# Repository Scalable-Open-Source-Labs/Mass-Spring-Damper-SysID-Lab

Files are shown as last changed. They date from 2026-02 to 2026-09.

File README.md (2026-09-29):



# Mass Spring Damper SysID Lab

A low-cost dynamics lab that allows students to perform System Identification on a real Mass-Spring-Damper system.

This is the source repo where you can download files for manufacturing: hardware, firmware, and enclosure design files. If you're looking for usage instructions or lab notes, head to the [user guide](https://monasheng.gitbook.io/scalable-labs/mass-spring-damper-sysid).

*Designed by Michael Ruppe for Monash University in partnership with MathWorks®*

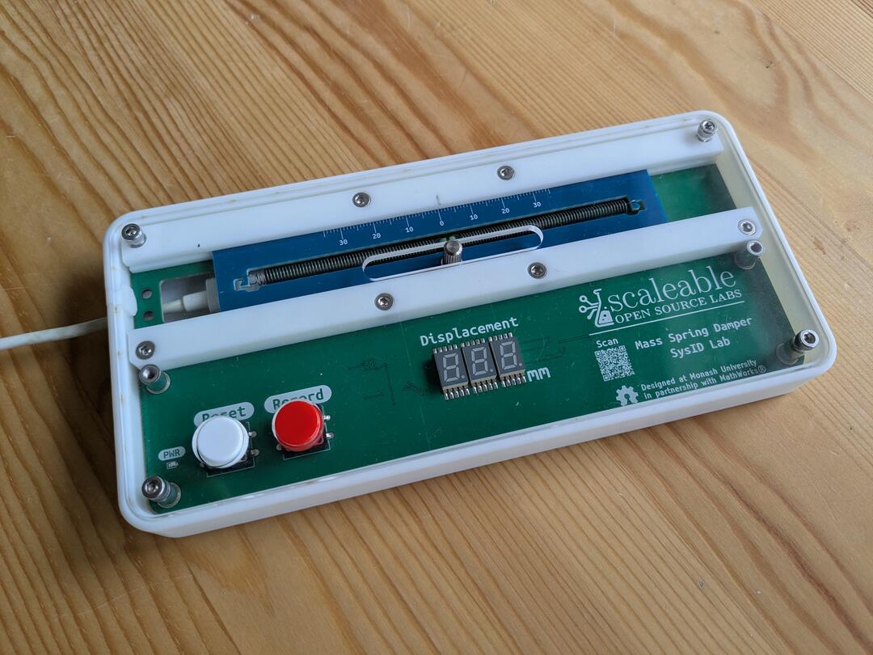
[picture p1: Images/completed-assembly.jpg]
Mass-spring-damper system diagram


## Repo map

| Path | What it is |
|---|---|
| [`PCB/`](PCB/README.md) | KiCad hardware source for the main board and carriage |
| [`Enclosure/`](Enclosure/README.md) | 3D-printable case, guide rail, and lasercut acrylic lid |
| [`firmware-mass-spring-damper-sys-id-lab/`](firmware-mass-spring-damper-sys-id-lab/README.md) | Arduino sketch for the RP2040 main board |
| [`Images/`](Images/) | Photos used in the assembly guide |
| [`Assembly-Instructions.md`](Assembly-Instructions.md) | Step-by-step mechanical build guide |
| [`Programming-Instructions.md`](Programming-Instructions.md) | Flashing and firmware dev setup |
| [`Ordering-Instructions.md`](Ordering-Instructions.md) | Bill of materials and where to order/fabricate each part |
| [`JLCPCB-Ordering-Instructions.md`](JLCPCB-Ordering-Instructions.md) | Step-by-step JLCPCB order for the fabricated and assembled boards |
| [`RELEASING.md`](RELEASING.md) | Maintainer checklist for cutting a tagged release |

## Getting started

- [Ordering Instructions](Ordering-Instructions.md)
  - [JLCPCB Ordering Instructions](JLCPCB-Ordering-Instructions.md)
- [Assembly Instructions](Assembly-Instructions.md)
- [Programming Instructions](Programming-Instructions.md)
- [Latest Project Release](https://github.com/Scaleable-Open-Source-Labs/Mass-Spring-Damper-SysID-Lab/releases/latest) - A downloadable bundle of all project files to complete this project: 3D Printing, PCBA, Lasercutting

## License

This project is licensed under the [MIT License](LICENSE).

Bundled third-party content — KiCad symbol/footprint libraries and vendor 3D step models under `PCB/main-board/packages3D/` and `PCB/carriage/CAD/`, and the patched `LedControl` fork used by the firmware (see [firmware README](firmware-mass-spring-damper-sys-id-lab/README.md)) — retains its original license terms.

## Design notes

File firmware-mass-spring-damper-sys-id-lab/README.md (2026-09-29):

# Firmware

Arduino sketch for the RP2040 main board. It reads the linear encoder as the carriage moves, drives the 7-segment display, and exposes the captured motion data as a CSV over USB. The board enumerates as a mass-storage drive, so data can be pulled off without any host-side software.

For build/flash setup (Arduino IDE, board settings, library versions) and calibrating a unit whose encoder misbehaves, see [Programming-Instructions.md](../Programming-Instructions.md).

The calibration maths and the encoder decoder have host tests that run on a PC. See [firmware-tests](../firmware-tests/README.md).

## Files

| File | Role |
|---|---|
| `firmware-mass-spring-damper-sys-id-lab.ino` | Main sketch: mode state machine, encoder capture, CSV data buffer, test mode |
| `gpio.cpp` / `gpio.h` | Pin definitions and GPIO init for the encoder, button, and display. Per-channel comparator thresholds (PWM through an RC filter) and sensor voltage readings (ADC) |
| `calibration.cpp` / `.h` | Per-unit threshold calibration, saved to emulated EEPROM |
| `sweep.cpp` / `.h` | Calibration-mode sweep recording and analysis: where each comparator actually switches, the width of each encoder state, and the thresholds that space the edges best |
| `LedControlPatched.cpp` / `.h` | Fork of the [LedControl](https://wayoda.github.io/LedControl/) library, with local modifications, used to drive the 7-segment display |
| `ramdisk.h` | USB Mass Storage (virtual FAT drive) implementation used to export captured data as a CSV file. The 32 KB image holds about 2,500 rows; `generateCSV()` stops at the last whole row that fits and reports it on serial |

## Encoder thresholds

Each optical channel's comparator switches at its own threshold, set by PWM through a 10k/1µF filter. An uncalibrated unit uses 780 mV on every channel (`VREF_DEFAULT_MV` in `gpio.h`).

The three channels form a 6-state Johnson code, and each state should span 1 mm of the 6 mm strip period. Robustness is the width of the narrowest state. When it reaches 0, two channels switch at the same place and a count can be lost.

A threshold moves its channel's two edges in opposite directions, so thresholds can only trade width between opposite states (100/011, 110/001, 111/000). The narrowest state is widest when every channel reads light for exactly half of each period (50% duty).

Calibration therefore sets each channel's threshold for 50% duty, measured from a sweep. This is not the midpoint of the channel's light and dark levels:
- The light level clips, because the phototransistor saturates near 220 mV. That lifts the midpoint, so a midpoint threshold makes every channel light for more than half the period.
- Calibration version 1 used the midpoint, and on a clipping sensor it pushed two channels' edges together. Units calibrated that way revert to the defaults (`CAL_VERSION` 2).

The rules:
- Each switching point stays at least 200 mV inside the sweep's light and dark levels (`MIN_MARGIN_MV` in `sweep.h`). If 50% duty lies outside that window, the threshold stops at the margin.
- When a margin stops a channel short of 50%, the others give way. Pushing them to 50% regardless would squeeze a state between them and the stuck channel.
  - Calibration starts from 50% duty, or from the thresholds already running if those space the edges better.
  - A search then moves each threshold within its margins while the simulated narrowest state keeps widening.
  - On board 1, A and B clip so hard that 50% is out of reach, so C ends up a little under 50%. That takes the narrowest state from about 0.87 to 0.92 mm.
- A channel whose light and dark levels are closer than 500 mV is refused (`MIN_SPAN_MV`).
- Before saving, the comparators are simulated over the recorded sweep at the new thresholds. Calibration is refused unless every period decodes cleanly and every state is at least 0.5 mm wide (`MIN_STATE_WIDTH_MM`).
- The comparators' hysteresis isn't assumed. Every sweep measures where each comparator actually switched, and the simulation and the margins use those points. The nominal 100 mV band (330k feedback, `COMPARATOR_HYST_MV` in `gpio.h`) is only the fallback for a channel that didn't switch.

The thresholds, and the light and dark levels, are saved with a CRC in emulated EEPROM (the last 4 KB of flash), which UF2 firmware updates leave alone.

If you change the `Calibration` struct in `calibration.cpp`, or the meaning of its fields, bump `CAL_VERSION`. Every unit then falls back to 780 mV until it is recalibrated.

## Calibration Mode

Hold **Record** at power-up or reset.

**Display**
- `CAL` (calibrated) or `dEF` (default thresholds) on entry.
- Then one digit per channel, with A on the right: the top segment when the comparator output is high, the bottom segment when it's low.
- Tap **Record** to start recording a sweep (all decimal points lit), and tap again to stop.
- Hold **Record** for 2 seconds to calibrate from the recorded sweep: `CAL` when saved, `Err` when refused.

**Serial** (USB, any baud rate)
- Streams the sensor voltages and thresholds in mV at 20 Hz, in the Arduino IDE 2 Serial Plotter format: `A:812,B:790,C:1020,VrefA:780,VrefB:780,VrefC:780`.
- Ending a recording prints a `#` summary. Each channel's line has, in mV:
  - the light (`min`) and dark (`max`) levels;
  - where the comparator switched at the current threshold (`rise`, `fall` and the band between them, `hyst`), with `hyst_src=meas` when measured from the sweep;
  - the margins those leave to the light and dark levels.

  It also gives:
  - `duty`, the fraction of each period the channel read light (`none` if the sweep was too short to measure it);
  - `half`, the threshold that makes it 0.5 (`clamped=light|dark` means a margin stopped it);
  - `suggest`, the threshold calibration would save.
- Then the width of each encoder state in mm, ideally 1 each:
  - `# hw` is measured from the comparators during the sweep.
  - `# sim` is simulated at the current thresholds, and should match `hw`.
  - `# half` and `# suggest` are simulated at the half-duty and suggested thresholds.
  - `min` is the narrowest state, the robustness figure.
  - `best` is what thresholds alone could reach, given where the sensors sit. `min` well below `best` points at the thresholds; both low points at the mechanics.
  - States are written with A as the left bit, so `w100` has A on a light stripe.
- The last line gives the position and the decoder's `recovered` and `lost` counts.
- The measurements are time-based, so sweep at a steady pace: about 2 seconds end to end, several times. Very slow sweeps are less accurate, because a hand's wobble is then a large fraction of the speed.
- Commands, one per line:
  - `A 820` (or `B`, `C`) sets that channel's threshold in mV until reset, without saving it.
  - `S` toggles the stream.
  - `X` clears the saved calibration.
- Lines starting with `#` use `key=value` tokens so the Serial Plotter ignores them.

In normal operation, each capture ends with `Done, N skipped states recovered, M counts lost` on serial.
- In the Johnson code, a jump of two states is unambiguous. It can come from a state the loop missed, or from two channels' edges crossing. The decoder counts it as ±2 instead of losing it, so a recovered skip costs a momentary 1 mm, seen as a 2 mm step in one CSV row.
- Only a jump to the opposite state, whose direction is unknown, loses counts. `lost` above 0 means the position is wrong.
- A steady nonzero `recovered` still means two edges sit close together. Check the unit's state widths in calibration mode.

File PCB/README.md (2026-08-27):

# PCB

## KiCad Projects

| Project | Purpose |
|---|---|
| [`main-board/`](main-board/) | RP2040 controller board. Reads the linear encoder, drives the 7-segment display, exposes captured motion data over USB as a virtual FAT12 drive |
| [`carriage/`](carriage/) | The moving carriage PCB that rides the guide rail, carrying the linear encoder strip |

## Datasheets

[`Datasheet/`](Datasheet/) Each schematic symbol's `Datasheet` field links to it with a path relative to its own project folder (e.g. `../Datasheet/SMTSO.pdf`), so this directory should only ever contain files that a `.kicad_sch` actually references. Call up a datasheet from within the schematic editor by hovering over a symbol and pressing the 'D' key.

Datasheets for parts that aren't placed as KiCad components (hand-assembly hardware sourced in [Ordering-Instructions.md](../Ordering-Instructions.md), like the carriage-capture bolt) belong in the root [`Datasheets/`](../Datasheets/) directory instead, not here.

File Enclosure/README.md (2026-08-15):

# Enclosure

Mechanical parts for the lab enclosure. Source models are maintained in OnShape — see the [OnShape project](https://cad.onshape.com/documents/9c2f20cdbdc0ad1f01a0b817/w/781d57bc81f27fd7521e8d8c/e/460a2fa13b5ff0fbf298da99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), fork it if you need to modify the design.

| File | Part | Process |
|---|---|---|
| [`Case - Resin Print.stl`](Case%20-%20Resin%20Print.stl) | Main case | Resin print |
| [`Guide Rail variant-hrs20-cwc09 - Resin Print.stl`](Guide%20Rail%20variant-hrs20-cwc09%20-%20Resin%20Print.stl) | Guide rail the carriage rides on | Resin print |
| [`Spacer - FDM or Resin Print.stl`](Spacer%20-%20FDM%20or%20Resin%20Print.stl) | Spacer (qty 2 per unit) | FDM or resin print |
| [`Lid - Lasercut Acrylic - Clear 3mm/`](Lid%20-%20Lasercut%20Acrylic%20-%20Clear%203mm/) | Lid, with cut drawing (`Lid.pdf`) and dimensions (`Lid-dimensions-and-notes.png`) | Lasercut, 3mm clear acrylic |

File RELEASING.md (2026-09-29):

# Releasing

A release is a tagged, tested snapshot containing only what's needed to manufacture and program one unit — not the KiCad/OnShape/firmware source. Source stays in the repo, for anyone who wants to inspect or fork the design; the release is for someone who just wants to build one.

## What a release contains

| Asset | Source |
|---|---|
| `firmware-{tag}.uf2` | Compiled from `firmware-mass-spring-damper-sys-id-lab/` |
| `main-board-fab-{tag}.zip` | Gerbers + BOM + CPL, regenerated fresh via the Fabrication Toolkit (see [PCB/README.md](PCB/README.md)) |
| `carriage-fab-{tag}.zip` | Same, for `PCB/carriage/` |
| `Case-{tag}.stl` | [`Enclosure/Case - Resin Print.stl`](<Enclosure/Case - Resin Print.stl>) |
| `Guide-Rail-{tag}.stl` | [`Enclosure/Guide Rail variant-hrs20-cwc09 - Resin Print.stl`](<Enclosure/Guide Rail variant-hrs20-cwc09 - Resin Print.stl>) |
| `Spacer-{tag}.stl` | [`Enclosure/Spacer - FDM or Resin Print.stl`](<Enclosure/Spacer - FDM or Resin Print.stl>) |
| `Lid-{tag}.pdf` | [`Enclosure/Lid - Lasercut Acrylic - Clear 3mm/Lid.pdf`](<Enclosure/Lid - Lasercut Acrylic - Clear 3mm/Lid.pdf>) |
| `Lid-dimensions-and-notes-{tag}.png` | [`Enclosure/Lid - Lasercut Acrylic - Clear 3mm/Lid-dimensions-and-notes.png`](<Enclosure/Lid - Lasercut Acrylic - Clear 3mm/Lid-dimensions-and-notes.png>) — include alongside `Lid-{tag}.pdf`, it's the sanity-check reference a cutting service uses to confirm scale/orientation |

`{tag}` is the release tag (e.g. `release-2026-08-16`) and goes on every asset uniformly, enclosure files included — they're just as versioned as the firmware or fab outputs, they'd just been missing the label. This is one shared label applied mechanically to everything in the release, not a per-file judgment call. It's also the only version baked into a filename: firmware's own internal `VERSION_MAJOR`/`VERSION_MINOR` stays out of asset names (it's already recorded in the release notes below, and in the binary itself) rather than mixing two numbering schemes into one string.

**Not included as files:** `Assembly-Instructions.md`, `Ordering-Instructions.md` and `JLCPCB-Ordering-Instructions.md`. All use paths relative to the repo (the assembly guide embeds images from `Images/`; the ordering doc links to `Enclosure/`, `PCB/README.md`, `Datasheets/`; the JLCPCB guide embeds images from `Images/ordering/`) — copying just the `.md` file into a flat release bundle breaks those links and the images render as missing. Instead, link both from the release notes as GitHub blob URLs pinned to the release tag (see template below) — GitHub resolves the relative image paths correctly when viewing a file at a specific ref, so the docs stay fully working without duplicating `Images/` into every release.

## Versioning

The release tag is its own product-level version, deliberately a different shape from the firmware version or the hardware revision — those move independently between releases (firmware `VERSION_MAJOR`/`VERSION_MINOR` in the `.ino`; hardware revision in the KiCad title block, currently `rev "1.2"` on `main-board`), and a bare `X.Y` tag would be indistinguishable from either at a glance. The tag just means "this combination was built and tested together." Record both underlying numbers in the release notes so anyone can trace a release back to exactly what it bundled.

**Tag format: `release-YYYY-MM-DD`** (e.g. `release-2026-08-16`), the date the release is cut. This repo isn't expected to release on any regular cadence — it'll mostly settle into a stable source repo after the first couple of releases — so the tag just records when, with no cadence implied. On the rare occasion two releases land the same day, append a letter (`-a`, `-b`).

## Steps

1. Confirm the working tree is clean and everything intended for this release is merged to `main`.
2. Regenerate PCB fab outputs fresh — for both `main-board` and `carriage` — via the KiCad Fabrication Toolkit plugin. Never reuse a local `production/` folder left over from earlier work; it may predate a schematic edit.
3. If firmware changed since the last release, bump `VERSION_MAJOR`/`VERSION_MINOR` in the `.ino` and commit that before tagging.
4. Compile the firmware and confirm the `.uf2` runs on real hardware.
5. Rename the generated files to match the naming convention above and zip the two fab-output folders.
6. Create the release commit. If necessary, create an empty commit to tag, when the release is a snapshot of work spread across many prior commits. It may not be the deliverable of whichever commit happens to be last, so it gets its own marker rather than borrowing an unrelated commit's meaning:
   ```
   git commit --allow-empty -m "Release release-2026-08-16"
   git tag release-2026-08-16
   git push origin main
   git push origin release-2026-08-16
   ```
7. Create the GitHub Release from that tag. Write release notes from the template below.
8. Attach all assets from the table above.
9. Publish.

## Release notes template

```md
## release-2026-08-16

Firmware: vA.B
Hardware: main-board revC.D, carriage revE.F

### What's in this release
Manufacturing and programming files only — gerbers/BOM/CPL for JLCPCB, 3D print and
laser-cut files, and a compiled firmware binary. For KiCad/OnShape source, clone the repo.

### What changed
Anything a builder needs to know before ordering or assembling — new/changed/removed parts,
sourcing changes, fit or compatibility notes for anyone with an already-built unit.

### Instructions
- [Ordering Instructions](https://github.com/Scaleable-Open-Source-Labs/Mass-Spring-Damper-SysID-Lab/blob/release-2026-08-16/Ordering-Instructions.md)
- [JLCPCB Ordering Instructions](https://github.com/Scaleable-Open-Source-Labs/Mass-Spring-Damper-SysID-Lab/blob/release-2026-08-16/JLCPCB-Ordering-Instructions.md)
- [Assembly Instructions](https://github.com/Scaleable-Open-Source-Labs/Mass-Spring-Damper-SysID-Lab/blob/release-2026-08-16/Assembly-Instructions.md)
- [Programming Instructions](https://github.com/Scaleable-Open-Source-Labs/Mass-Spring-Damper-SysID-Lab/blob/release-2026-08-16/Programming-Instructions.md)
```

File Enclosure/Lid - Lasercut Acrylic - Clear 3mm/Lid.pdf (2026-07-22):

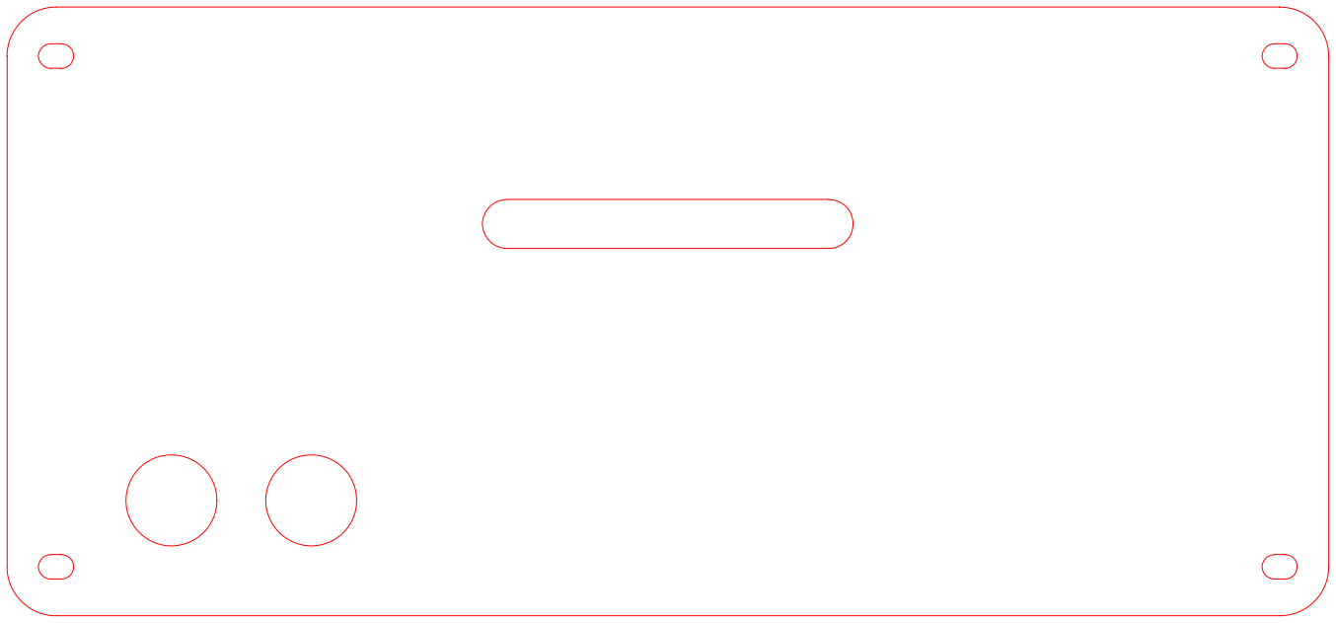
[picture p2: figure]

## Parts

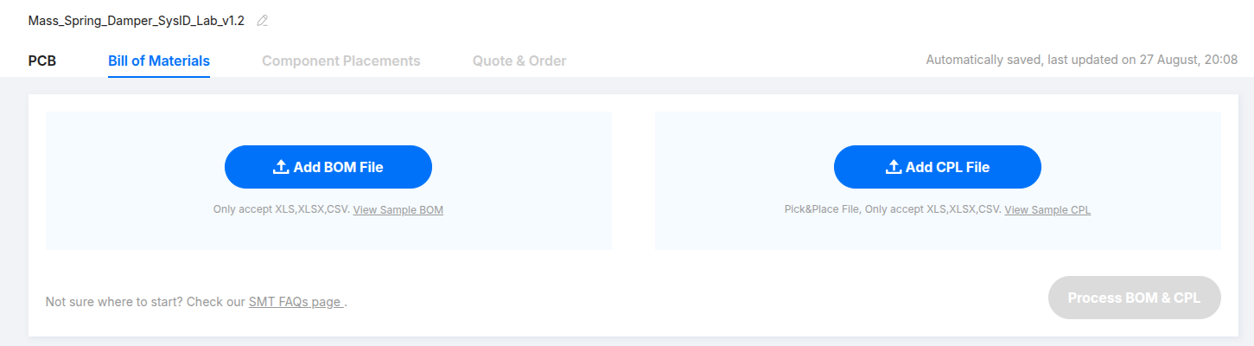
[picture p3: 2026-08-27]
Images/ordering/pcba-bom.png

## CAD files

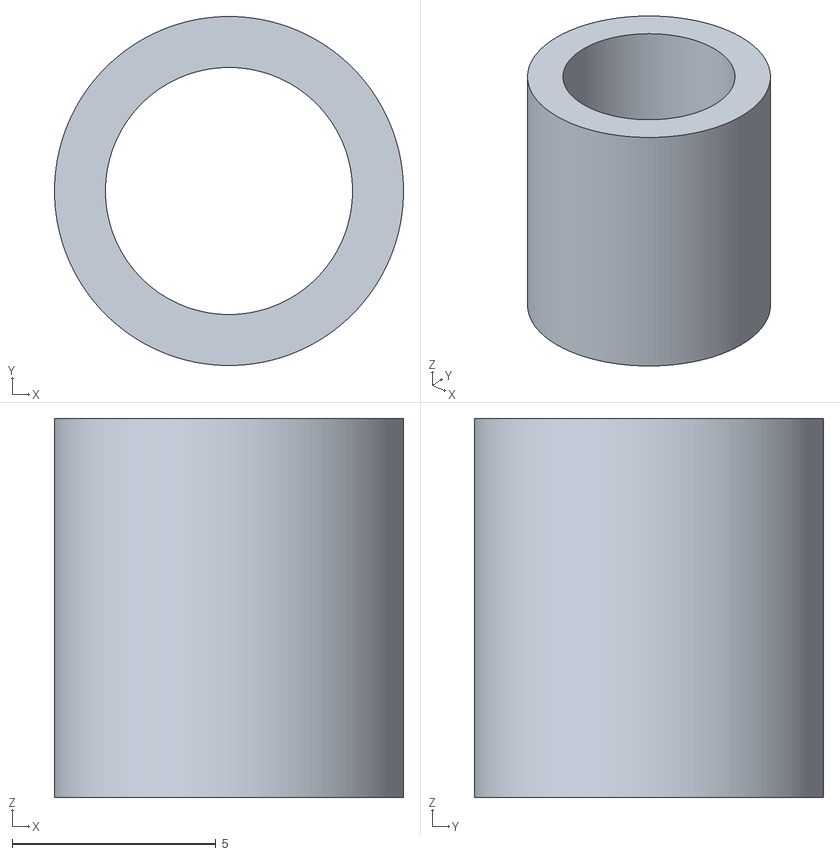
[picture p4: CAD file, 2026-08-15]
Enclosure/Spacer - FDM or Resin Print.stl
8.56 x 8.56 x 9.30

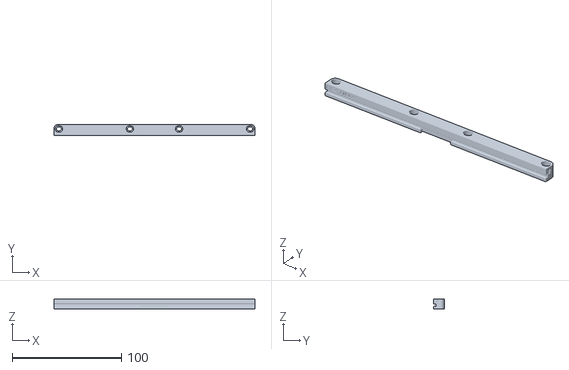
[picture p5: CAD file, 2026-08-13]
Enclosure/Guide Rail variant-hrs20-cwc09 - Resin Print.stl
184.0 x 10.0 x 9.50

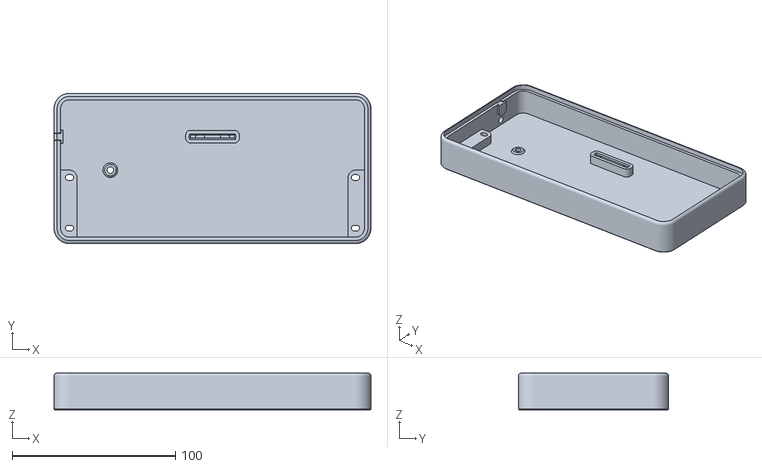
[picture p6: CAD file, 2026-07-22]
Enclosure/Case - Resin Print.stl
194.0 x 92.0 x 22.6

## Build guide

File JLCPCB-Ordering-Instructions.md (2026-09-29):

# JLCPCB Ordering Instructions

This is a step-by-step walkthrough of ordering the two circuit boards, fabricated and assembled, from [JLCPCB](https://jlcpcb.com). For everything else in the build, see [Ordering Instructions](Ordering-Instructions.md).

You place one order per board:

| Board | Soldermask | Silkscreen | Assembly side |
|---|---|---|---|
| Main board | White | Black | Both sides |
| Carriage | Red | White | Bottom side only |

The screenshots below are from a main board order. The carriage follows the same steps; its differences are listed in [Ordering the carriage](#ordering-the-carriage).

JLCPCB changes its ordering pages from time to time, so an option may have moved or been renamed. The settings are what matter.

## 0. Get the fabrication files

Download `main-board-fab-{tag}.zip` and `carriage-fab-{tag}.zip` from the [latest release](https://github.com/Scaleable-Open-Source-Labs/Mass-Spring-Damper-SysID-Lab/releases/latest) and unzip them. Each contains three files you'll upload:

| File | What it is | Uploaded in |
|---|---|---|
| `*.zip` (the gerbers) | The bare board: copper, soldermask, silkscreen, drill | Step 1 |
| `*_bom.csv` | Bill of materials: which real part goes at each designator | Step 6 |
| `*_positions.csv` | Placement (CPL): where each part sits and how it's rotated | Step 6 |

> **Maintainers:** if you've changed the KiCad design, regenerate these files with the KiCad Fabrication Toolkit plugin instead. Never reuse an old `production/` folder, because it may predate a schematic edit.

## 1. Upload the gerbers and set the quantity

On [jlcpcb.com](https://jlcpcb.com), upload the gerber zip. JLCPCB detects a 2-layer board and fills in the dimensions. Set **PCB Qty**.

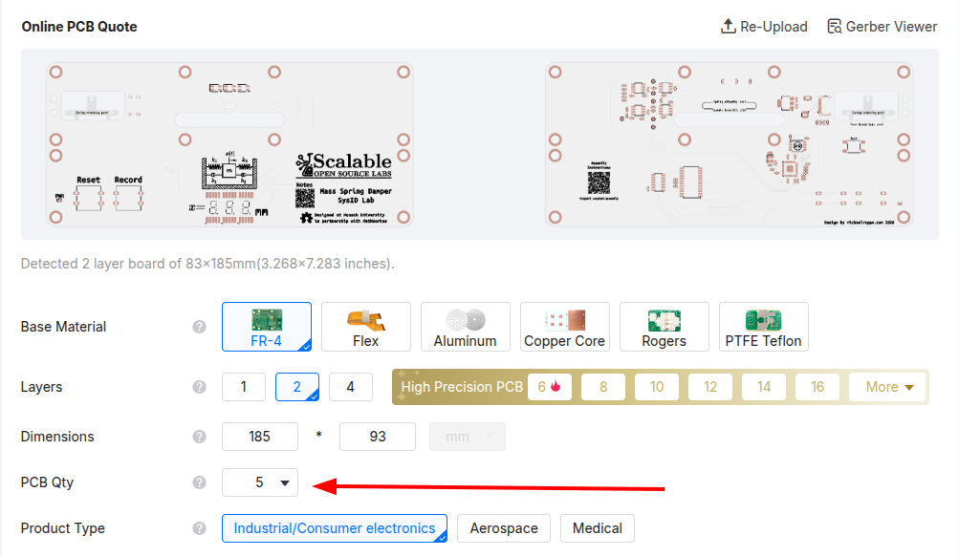
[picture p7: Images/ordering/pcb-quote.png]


## 2. PCB specifications

Set:

- **PCB Color:** White (main board)
- **Silkscreen:** Black (set automatically with white)
- **Surface Finish:** LeadFree HASL

Leave everything else at its default (FR-4, 2 layers, 1.6mm thickness, Single PCB).

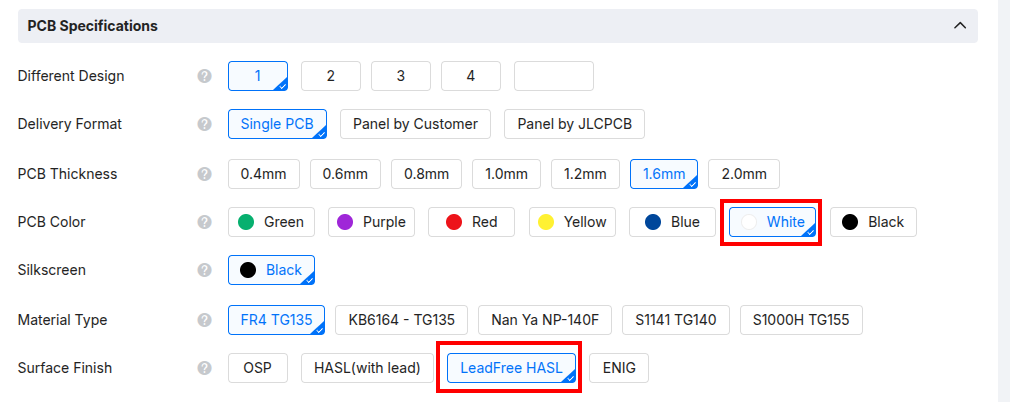
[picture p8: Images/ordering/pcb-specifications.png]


## 3. Turn on PCB assembly

Further down the page, switch on the **PCB Assembly** toggle, then set:

- **PCBA Type:** Standard
- **Assembly Side:** Both Sides (main board)
- **PCBA Qty:** the same as your PCB quantity
- **Edge Rails/Fiducials:** Added by JLCPCB. The board grows slightly with rails on the long sides. This is expected.
- **Parts Selection:** By Customer (Self-Service)

Leave Confirm Parts Placement, Stencil Storage and Fixture Storage at No.

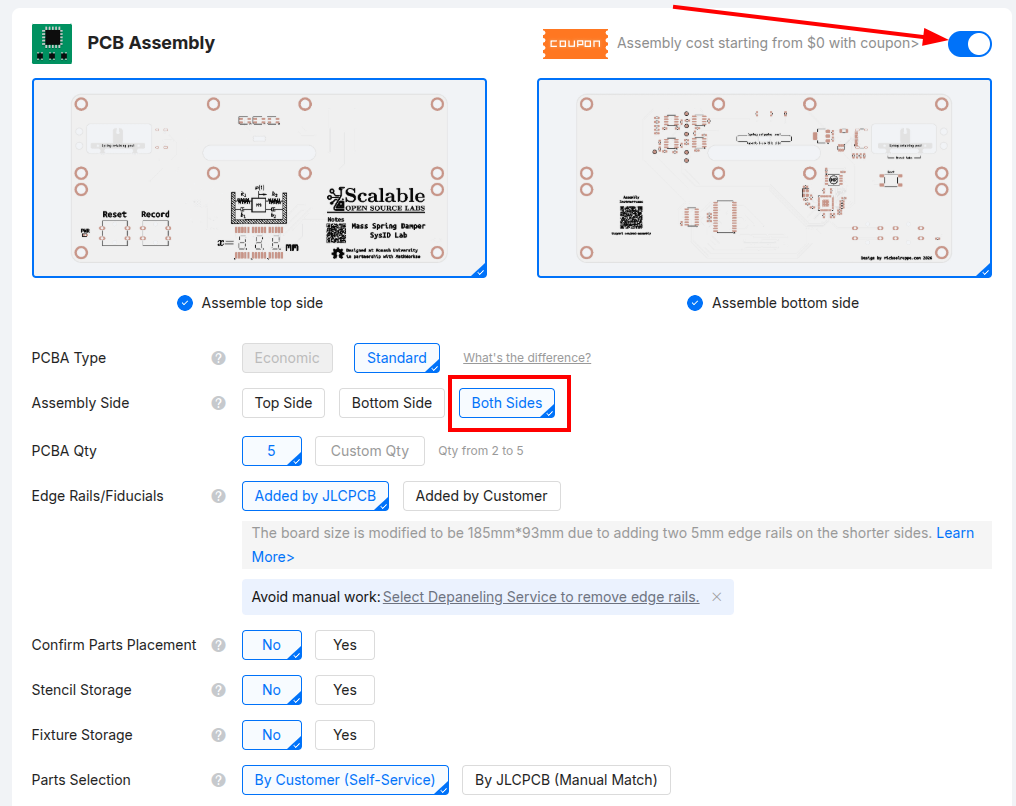
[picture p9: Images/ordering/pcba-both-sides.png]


## 4. Advanced options

Set **Depanel boards & edge rail before delivery** to **Yes**. 

**Optional**: Bake Components. The optical components are moisture sensitive (MSL4) and baking may lead to a lower failure-rate. If you select yes to this option, you will need to provide the reference for the three optical parts.

Leave the other advanced options at their defaults, then accept the assembly terms.

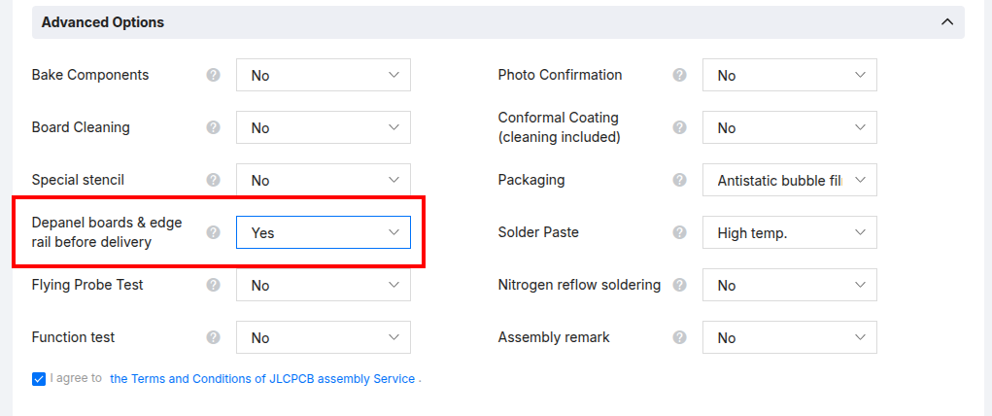
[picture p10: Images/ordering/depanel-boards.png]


## 5. Check the board render

Click through to the assembly pages. The first page shows a render of the board with a Top/Bottom toggle. Check both sides look right and that the PCBA type, assembly side and quantity match what you chose. Then click **Next**.

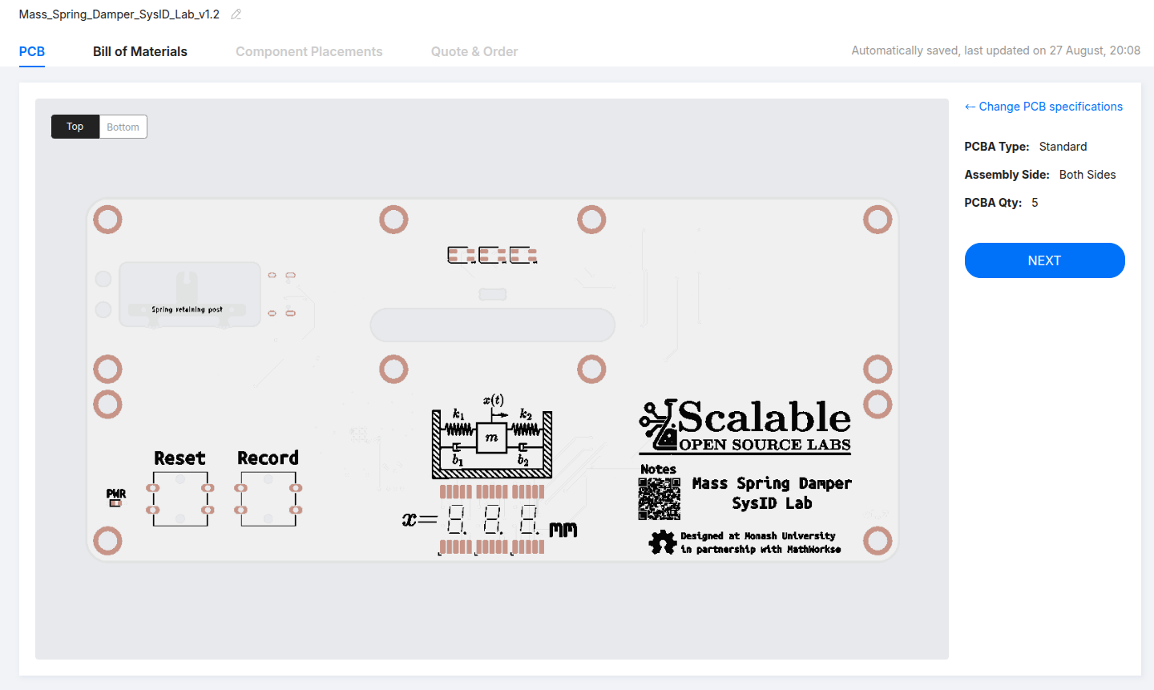
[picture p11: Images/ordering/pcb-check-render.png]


## 6. Upload the BOM and placement files

On the **Bill of Materials** tab, add the `*_bom.csv` as the BOM file and the `*_positions.csv` as the CPL file, then click **Process BOM & CPL**.

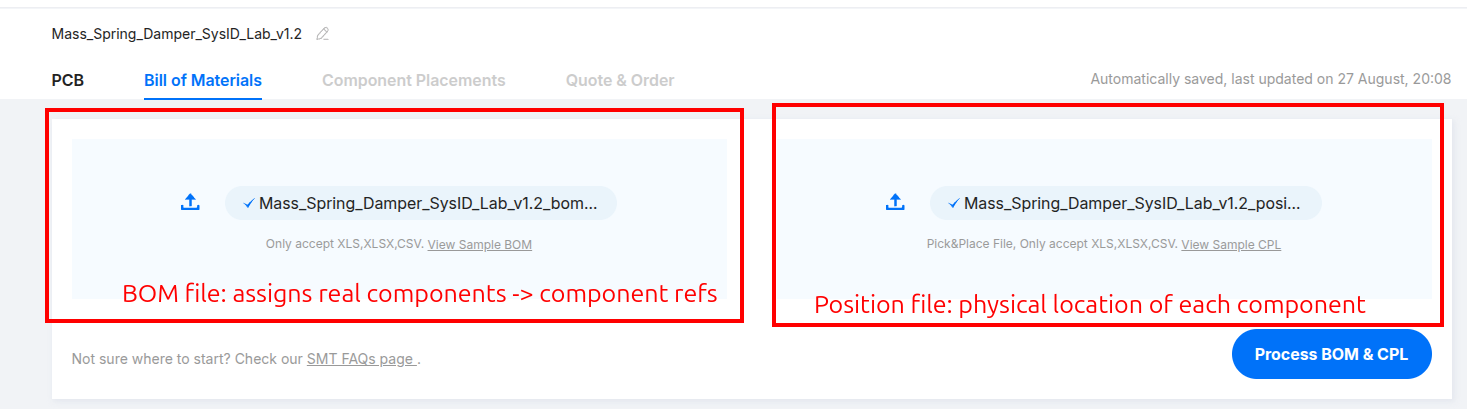
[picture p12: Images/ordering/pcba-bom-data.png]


## 7. Review the matched parts

JLCPCB lists every part it matched from your BOM. Check that **every row is ticked** in the Select column. An unticked row is left off the board.

Rows marked with a warning icon need a closer look. On past orders these were the USB-C connector (J1) and the two pushbuttons (SW2, SW3). Hover over the icon to read the warning, and make sure the row is still ticked before you continue.

Reason (USB-C connector): Complicated part requires special handling to place. Ensure box is checked.
Reason (SWitches): Each tactile button shares a different "Value" (Record/Reset) but the same component is assigned. That is fine. Ensure box is checked.

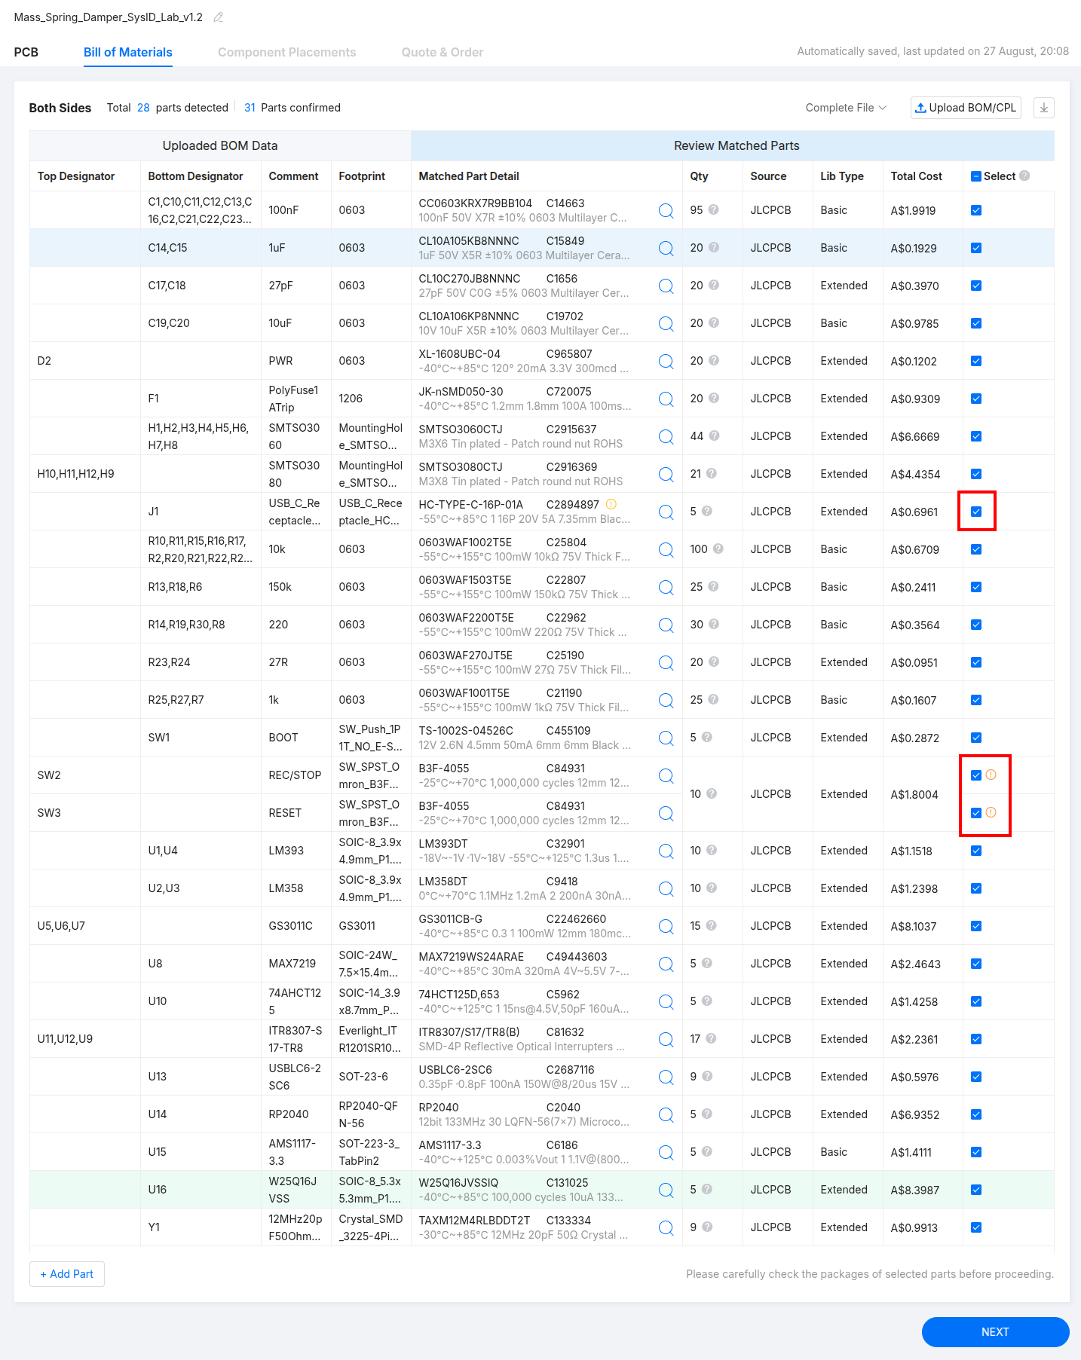
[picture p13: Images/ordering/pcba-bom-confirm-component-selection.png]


## 8. Check the component placements

This step catches most ordering mistakes. The **Component Placements** tab shows every part sitting on its pads in 3D. Several parts come out **rotated or offset** from where they belong, and JLCPCB assembles exactly what this view shows.

Step through **every part on both sides**. Pay particular attention to parts where orientation matters (ICs, sensors, diodes, connectors), and look for pin 1 markers that don't line up and bodies that overhang their pads. Fix each one before continuing.

The two examples below are from a v1.2 main board order. The parts that need fixing may differ on your board revision, so check them all rather than only these.

### Example: a rotated part

This optical sensor (U11) is placed 180° out: the pin 1 dot on the part is at the opposite end from the footprint's pin 1 marker (the magenta triangle).

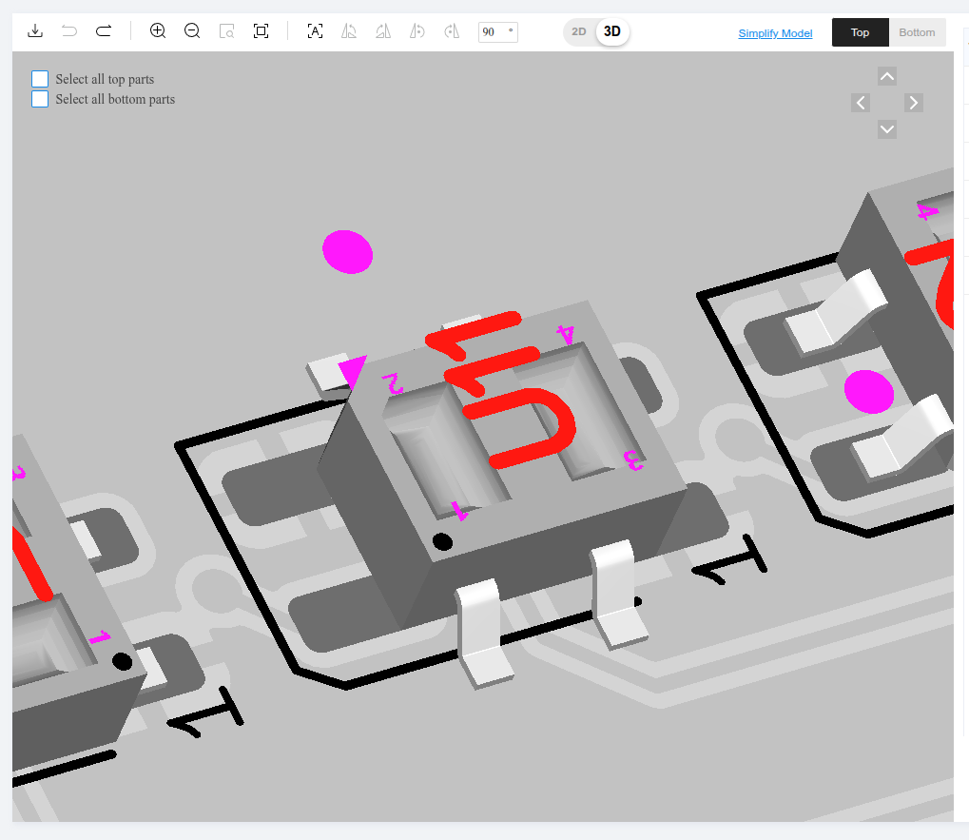
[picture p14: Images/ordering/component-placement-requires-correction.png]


Select the part and use the rotate buttons (boxed) until it lines up with the footprint:

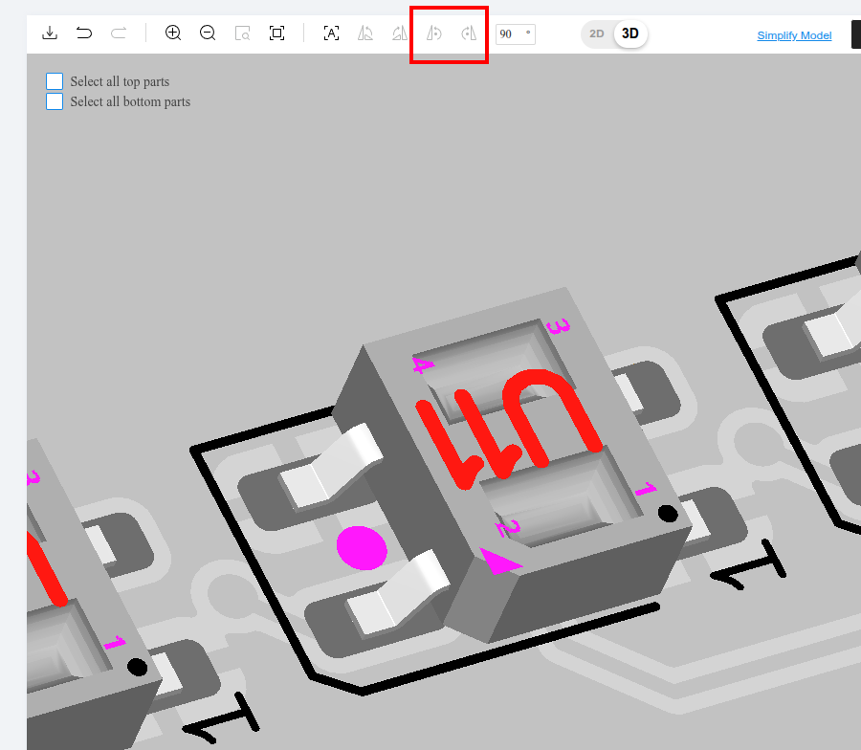
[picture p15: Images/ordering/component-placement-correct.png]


### Example: an offset part

The USB-C connector (J1, bottom side) sits too far right, off its pads:

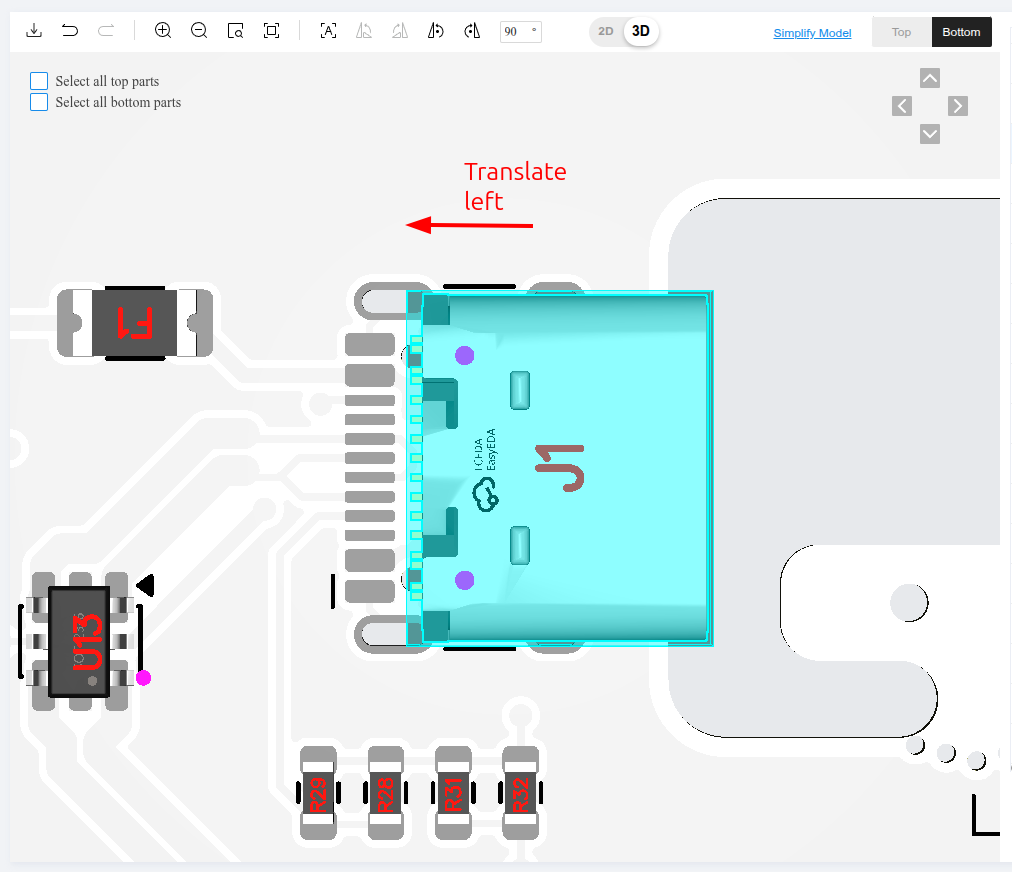
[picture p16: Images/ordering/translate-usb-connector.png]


Select it and move it left until its pins sit on the pads:

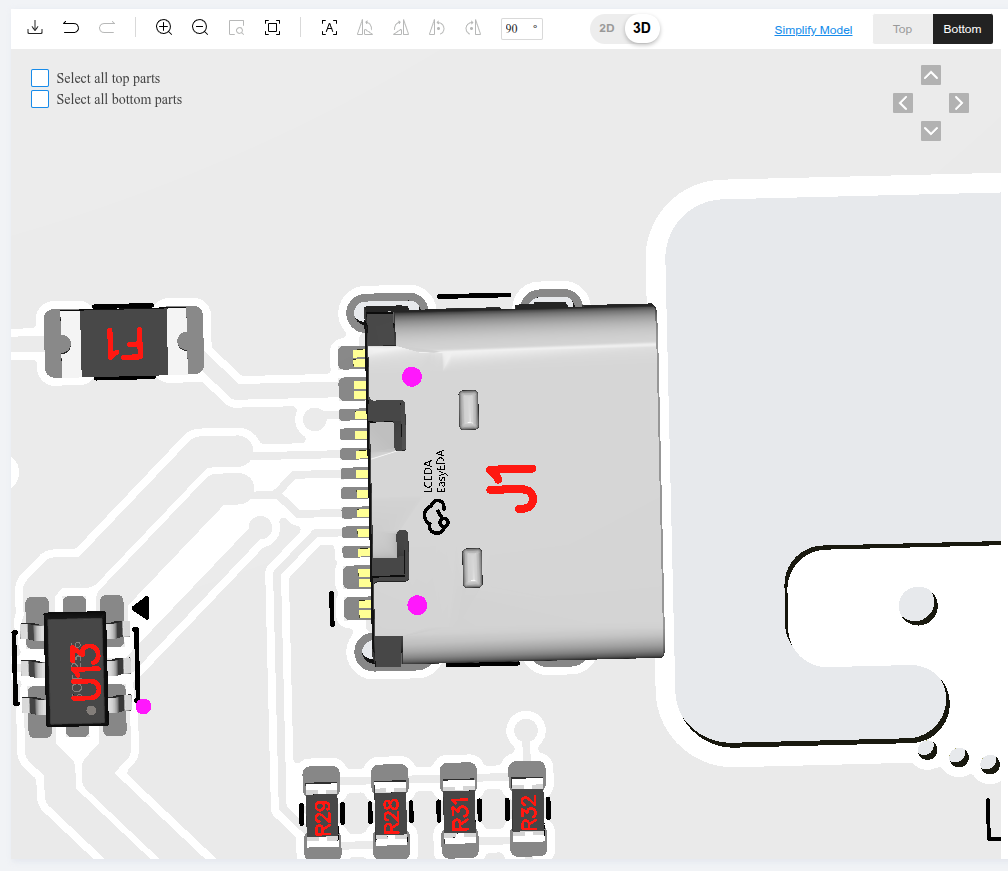
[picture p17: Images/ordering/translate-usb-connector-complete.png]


## 9. Quote and order

On the **Quote & Order** tab, review the price breakdown, add the order to your cart, and check out.

## Ordering the carriage

Place a second order for the carriage using the files from `carriage-fab-{tag}.zip`. Follow the same steps, with these differences:

| Step | Main board | Carriage |
|---|---|---|
| 2. PCB Color | White | **Red** |
| 2. Silkscreen | Black | **White** |
| 3. Assembly Side | Both Sides | **Bottom Side** |

Everything else is the same, including depanelling and checking every placement in step 8.

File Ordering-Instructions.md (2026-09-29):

# Ordering Instructions

Sourcing a complete lab unit means placing orders with a handful of different vendors and fabrication services — PCB assembly, 3D printing, laser cutting, and a few off-the-shelf hardware suppliers. This doc groups everything by where you'd actually order it from, so each section is one checkout.

Quantities below are **per unit**. Multiply for a batch build.

## Order at a glance

| Vendor / service | What you get |
|---|---|
| [JLCPCB](https://jlcpcb.com) | Main board + carriage, fabricated and assembled |
| [JLC3DP](https://jlc3dp.com) (or in-house printer) | Case + Guide Rail + Spacer |
| [acrylicsonline.com.au](https://www.acrylicsonline.com.au) | Lid, laser-cut from 3mm clear acrylic |
| [nhtb.com.au](https://nhtb.com.au) | M3 fasteners |
| JLCMC | Knurled carriage-capture bolt |
| LCSC Electronics | Button caps |
| [RS Components](https://au.rs-online.com) | Extension springs |
| [Core Electronics](https://core-electronics.com.au) | USB-C cable |
| Commodity / no fixed vendor | Cable tie, threadlocker |

---

## Fabrication services

### PCB fabrication & assembly — JLCPCB

| Board | Soldermask / silkscreen | Assembly | Qty |
|---|---|---|---|
| `PCB/main-board/` (DynaLab) | White / black | Both sides assembled | 1 |
| `PCB/carriage/` | Red / white | Bottom side only assembled | 1 |

Follow [JLCPCB Ordering Instructions](JLCPCB-Ordering-Instructions.md) for a step-by-step walkthrough of both orders, including the placement checks that catch rotated parts. Use the fab files from the latest release, not any BOM or gerber files you find lying around locally, so what you order matches the current design.

### 3D printing — JLC3DP or in-house

| Part | File | Process | Qty |
|---|---|---|---|
| Case | [`Enclosure/Case - Resin Print.stl`](Enclosure/Case%20-%20Resin%20Print.stl) | Resin | 1 |
| Guide Rail | [`Enclosure/Guide Rail variant-hrs20-cwc09 - Resin Print.stl`](Enclosure/Guide%20Rail%20variant-hrs20-cwc09%20-%20Resin%20Print.stl) | Resin | 2 (both guides are identical — print the same file twice) |
| Spacer | [`Enclosure/Spacer - FDM or Resin Print.stl`](<Enclosure/Spacer - FDM or Resin Print.stl>) | FDM or resin | 2 |

Production units were printed via [JLC3DP](https://jlc3dp.com). This is an open-source project, so if your institution has a suitable printer, printing in-house is equally valid — no need to use JLC3DP specifically.

### Laser cutting (acrylic) — acrylicsonline.com.au

| Part | File | Material | Qty |
|---|---|---|---|
| Lid | [`Enclosure/Lid - Lasercut Acrylic - Clear 3mm/Lid.pdf`](<Enclosure/Lid - Lasercut Acrylic - Clear 3mm/Lid.pdf>) | 3mm clear acrylic, clear | 1 |

Submit [`Lid-dimensions-and-notes.png`](<Enclosure/Lid - Lasercut Acrylic - Clear 3mm/Lid-dimensions-and-notes.png>) alongside the cut file — it's a useful sanity check for the cutting service to confirm the vector was interpreted at the right scale/orientation before they cut.

[acrylicsonline.com.au](https://www.acrylicsonline.com.au) supplies both the 3mm clear acrylic stock and the laser-cutting service at a reasonable price.

---

## Off-the-shelf parts

### Fasteners — nhtb.com.au

| Part | Qty | Used for |
|---|---|---|
| [SC M3x8 304](https://nhtb.com.au/SC%20M3X8%20304.html) (short) | 12 | Guide mounting (6), board-to-enclosure (4), lid (2) |
| [SC M3x16 304](https://nhtb.com.au/SC%20M3X16%20304.html) (long) | 2 | Lid (2) |

### Carriage-capture bolt — JLCMC

| Part | Part # | Qty | Used for | Datasheet |
|---|---|---|---|---|
| Knurled bolt | `ESLD-C2-M3-L6` | 1 | Captures the carriage in the guide rails | [`Datasheets/ESLD.pdf`](Datasheets/ESLD.pdf) |

### Button caps — LCSC Electronics

| Part | Part # | Qty | Used for |
|---|---|---|---|
| Button cap, red | `SC215AB1` | 1 | Record button |
| Button cap, white | `SC215AE1` | 1 | Reset button |

### Springs — RS Components

| Part | Qty |
|---|---|
| [Steel Extension Spring, 27.2mm x 4mm OD](https://au.rs-online.com/web/p/extension-springs/0751663) | 2 |

### USB-C cable — Core Electronics

| Part | Part # | Qty | Used for |
|---|---|---|---|
| USB-C cable | `CE09402` | 1 | Connects the main board to the host — secured internally with a cable tie, trimmed to length during assembly |

### Consumables — no fixed vendor

| Item | Qty | Notes |
|---|---|---|
| Cable tie | 1 | Bunnings I/N [4431099](https://www.bunnings.com.au/crescent-100mm-x-2-5mm-black-cable-ties-100-pack_p4431099). The locking mechanism must be no more than **4mm deep** (the axis through which the tail passes through) — oversized locking mechanisms mechanically foul against the enclosure during installation. Confirm this dimension against any candidate part before bulk ordering |
| Threadlocker — Loctite 242 (or equivalent medium-strength) | small qty | Recommended on the knurled carriage-capture bolt to prevent loosening in use |

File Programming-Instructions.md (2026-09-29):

# Programming Instructions

## Flashing a Pre-compiled binary (Drag-and-drop programming)
Use this method for batch programming, or for applying a firmware to a deployed unit.

Download the latest `.uf2` firmware file from the repository [Releases](https://github.com/Scaleable-Open-Source-Labs/Mass-Spring-Damper-SysID-Lab/releases/latest)

> Use the firmware from the same release as your circuit boards. Firmware 2.0 and later only work on main board rev 2.0. Earlier boards (main board rev 1.x, including the pilot run in release-2026-08-17) need the firmware from that release.

Connect to a host computer with the USB cable. Unprogrammed boards (fresh from factory) will automatically enter Firmware Update mode.
> Programmed Units:
> If the unit has been programmed before, the process is different. Hold down the button on the back of the device *and then* connect to the host computer. Once plugged in, release the button.

An external Drive `RPI-RP2` should appear

Copy the `.uf2` firmware file onto the `RPI-RP2` drive.

Once the file transfer is complete, the unit will automatically run the new firmware.

The programmed unit should now operate as described in the [User Instructions](https://monasheng.gitbook.io/scalable-labs/mass-spring-damper-sysid). Move the carriage and observe the displacement reading updates sensibly.

If the reading doesn't behave, calibrate the optical encoder next. A unit that behaves doesn't need it.

## Calibrating the optical encoder
Each unit requires calibration on it's first powerup after being programmed. Calibration tunes the unit to its own three optical sensors, which vary between production batches, so the displacement reading stays reliable. The calibration is stored on the unit (EEPROM) and kept through firmware updates. No computer is needed: the unit's display gives all the feedback.

Recalibrate if the circuit board or carriage is replaced, or if the displacement reading no longer returns to where it started +-1mm.

1. Hold down the **Record** button, then connect the USB cable (or press and release **Reset**). Keep holding **Record** until the display shows one of these, then release it:
    - `CAL`: the unit is already calibrated. Recalibrating is fine.
    - `dEF`: the unit isn't calibrated yet and is running default settings.

   After a moment, each digit shows one sensor as a bar at the top or bottom of the digit, which jumps as the carriage moves. Slowly sliding the carriage should make the bars ripple in a wavelike pattern.
2. Tap **Record**. All three decimal points light up: the unit is recording.
3. Slide the carriage from one end of its travel to the other and back, at a steady pace of about 2 seconds per slide. Do this at least four times (two round trips). Steady matters more than slow.
4. Hold **Record** until the display changes, about 2 seconds:
    - `CAL`: calibration saved.
    - `Err`: nothing was saved, and any earlier calibration is kept. Tap **Record** and repeat from step 3, making sure the carriage reaches both ends at a steady pace. If `Err` keeps appearing, the unit has a faulty or misaligned sensor.
5. Slide the carriage end to end again. All three digits should now jump between top and bottom. If one doesn't, the unit has a faulty sensor.
6. Press **Reset** to return to normal operation. From a zeroed position, pluck the carriage and it should return to zero or +- 1mm

> Do not perform the procedure on a 'naked PCB' where you might be able to touch the circuit board under the sensors or amplifier circuitry. Touching this area will invalidate the calibration.

## Batch Programming
Programming many units in a batch becomes tedious. The [batch-uf2](https://github.com/michaelruppe/batch-uf2) streamlines production programming of many units. It watches for a UF2 bootloader drive to appear, copies a firmware file to it, waits for the device to reset and disappear, then goes back to waiting. Repeats until you cancel it.

## IDE Programming
This method is for actively developing new code.

Requires:
- Arduino IDE
- Board profile: Raspberry Pi Pico/RP2040/RP2350 by Earle F. Philhower, III - v5.5.0 or newer. Refer to the [repo](https://github.com/earlephilhower/arduino-pico) for installation instructions.
- Libraries:
    - [Adafruit TinyUSB Library](https://github.com/adafruit/Adafruit_TinyUSB_Arduino) by Adafruit 3.7.4 or newer
    - [LedControl](https://wayoda.github.io/LedControl/) by Eberhard Fahle. 1.0.6 or newer

Use the following board settings (Tools > Board). Most settings are default. Settings that need attention are in **bold**

- **Board: Generic RP2040**
- **Port: UF2_Board** (this option may only be available once the device is connected, and in BOOT mode)
- **Boot Stage 2: W25Q64JV QSPI/4**
- Debug Level: None
- Debug Port: Disabled (never Serial1, whose pins carry encoder signals on rev 2.0 boards)
- C++ Exceptions: None
- Flash Size: 2MB (No FS)
- CPU Speed: 200MHz
- IP/Bluetooth Stack: IPV4 only
- Optimise: Small
- Operating System: None
- Profiling: Disabled
- RTTI: Disabled
- Stack Protector: Disabled
- Upload Method: Default (UF2)
- **USB Stack: Adafruit TinyUSB**

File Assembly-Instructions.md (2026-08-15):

Before you begin, order all parts — see [Ordering Instructions](Ordering-Instructions.md) for the full BOM grouped by vendor/fabrication service.

# Equipment required

- Safety glasses - **springs are under tension and may fly off mounts during assembly**.
- Pliers
- Side cutters
- Bit driver with 2.5mm hex bit

# Assembly Instructions

## Snap parts off circuit board

Carefully snap off the following parts from the circuit board:

1. Edge rails. These can be discarded
2. Spring retainer. Install this into the enclosure's slot to keep safe, and set aside.

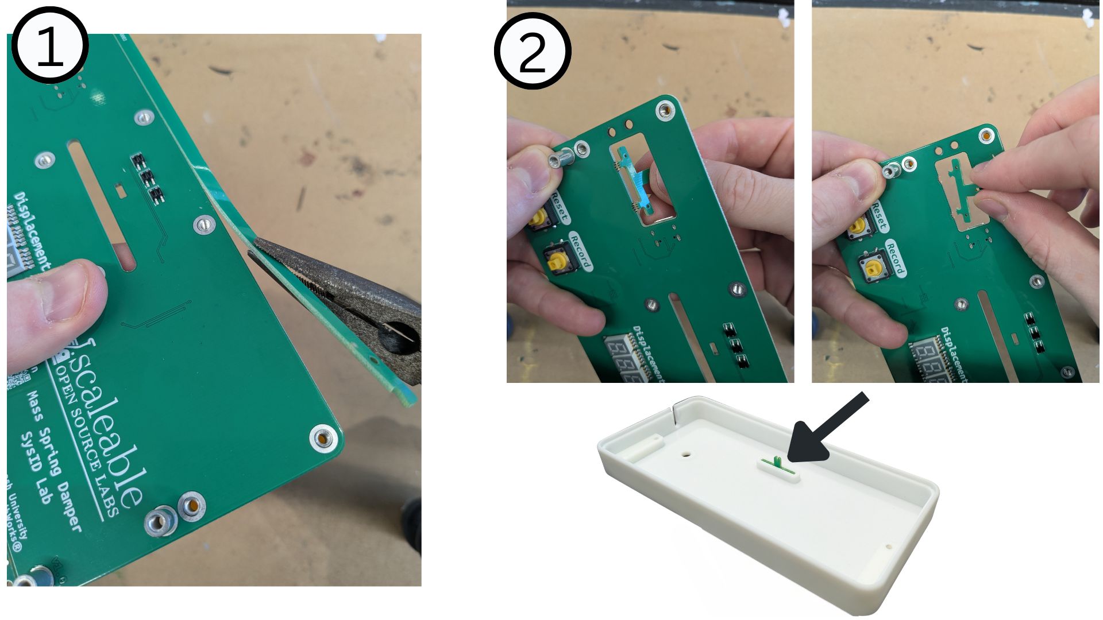
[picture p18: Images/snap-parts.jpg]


## Mount guides

Use 6x short (M3x8mm) screws to secure the guides to the circuit board. Both guides are identical.
Ensure the arrows point upwards.

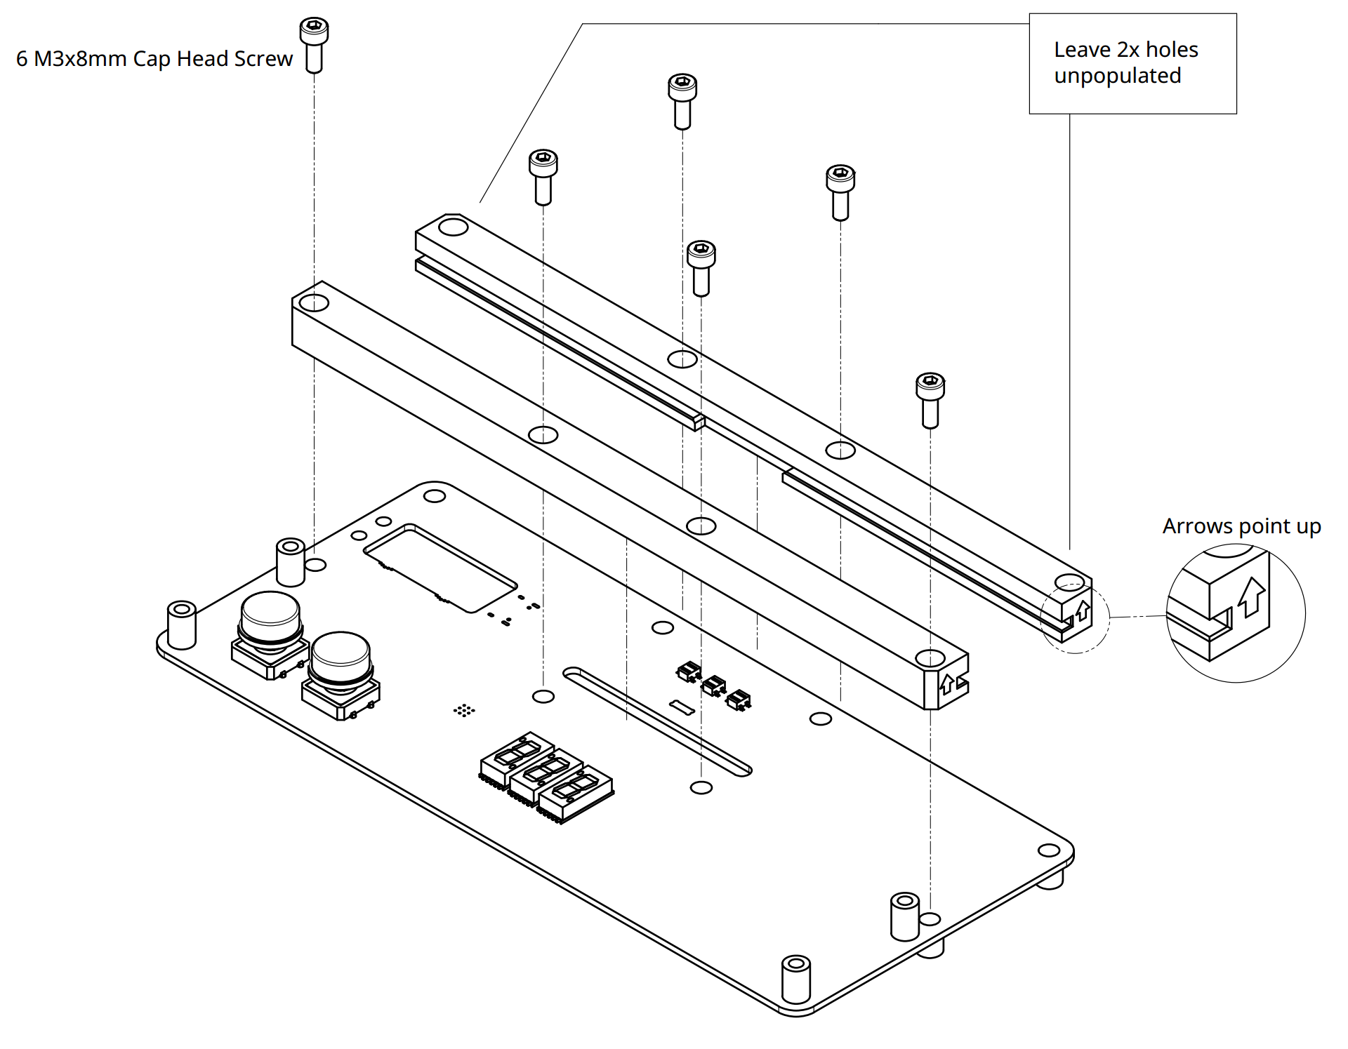
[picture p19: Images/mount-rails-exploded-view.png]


## Install Carriage

- Slide the carriage into the guides. Ensure orientation of carriage graduation numbers is correct.
- Centre the carriage and install the knurled screw. This will capture the carriage and prevent it falling out. Pliers may be helpful for torquing the screw. Consider adding a tiny drop of superglue or blue Loctite to prevent screw from loosening.

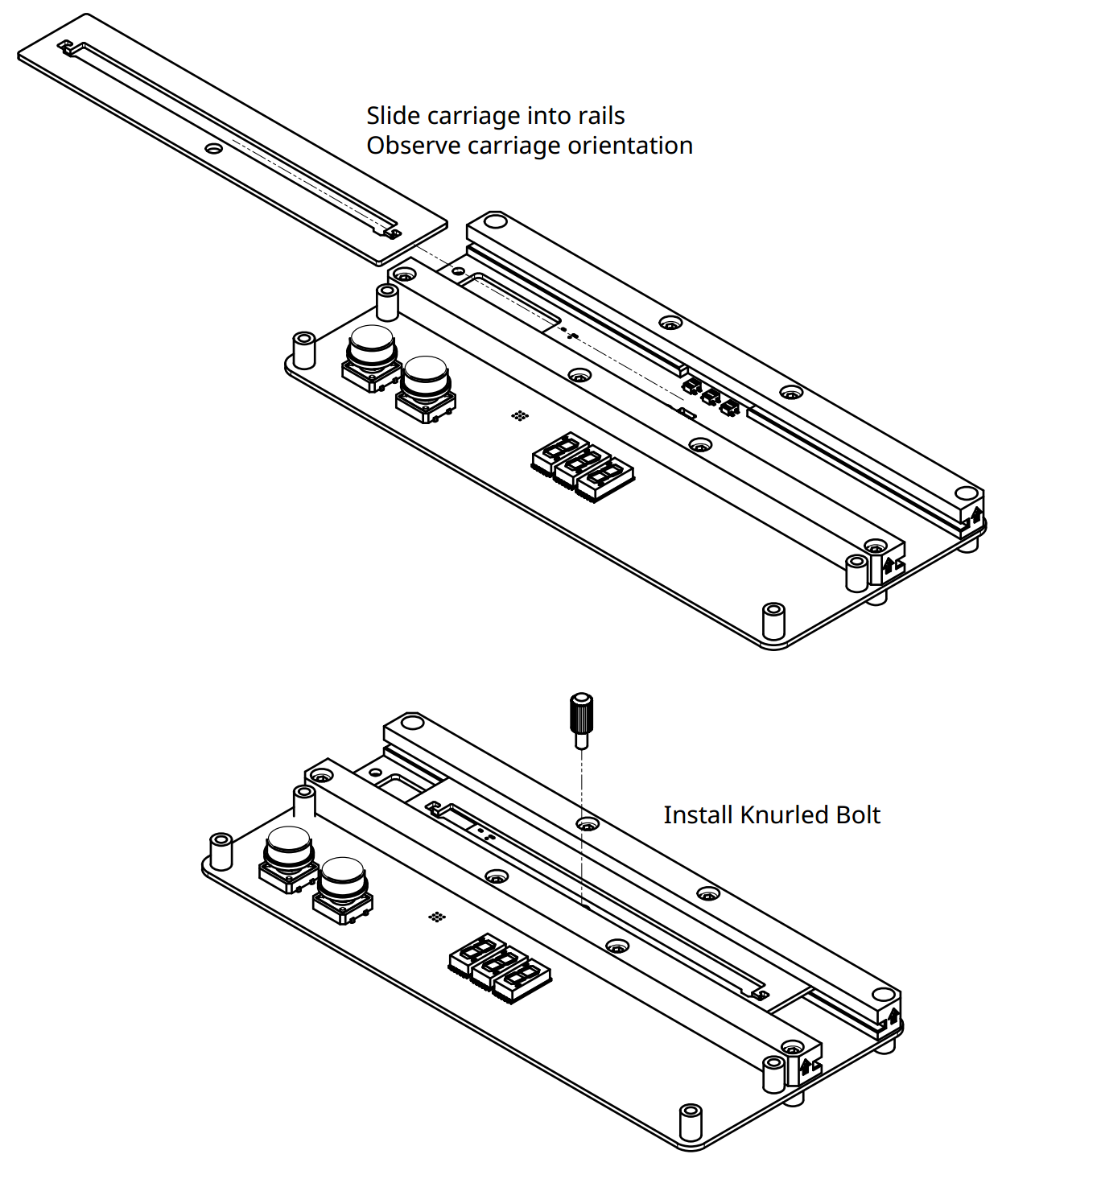
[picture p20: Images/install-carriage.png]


## Fix USB cable to circuit board

1. Plug one end of a USB-C cable into the circuit board.
2. Secure with a cable tie. The locking mechanism must be located on the same side of the circuit board as the USB connector.
3. Trim excess.
4. Ensure that no sharp plastic remains.

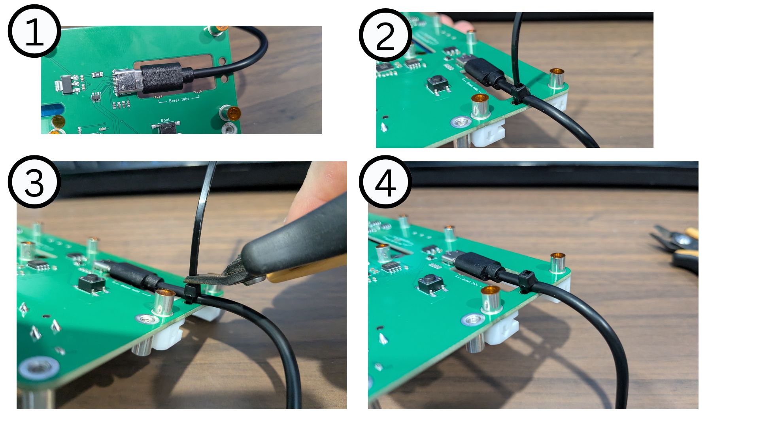
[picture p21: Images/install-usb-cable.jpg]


## Mount circuit board into enclosure

Carefully snap out the cable blanking plate and set aside.

Insert the circuit board into the enclosure:
- Guide the spring retainer through the rectangular hole in the circuit board.
- Seat the USB cable into the cable slot

Use 4x short (M3x8mm) screws to secure circuit board into enclosure

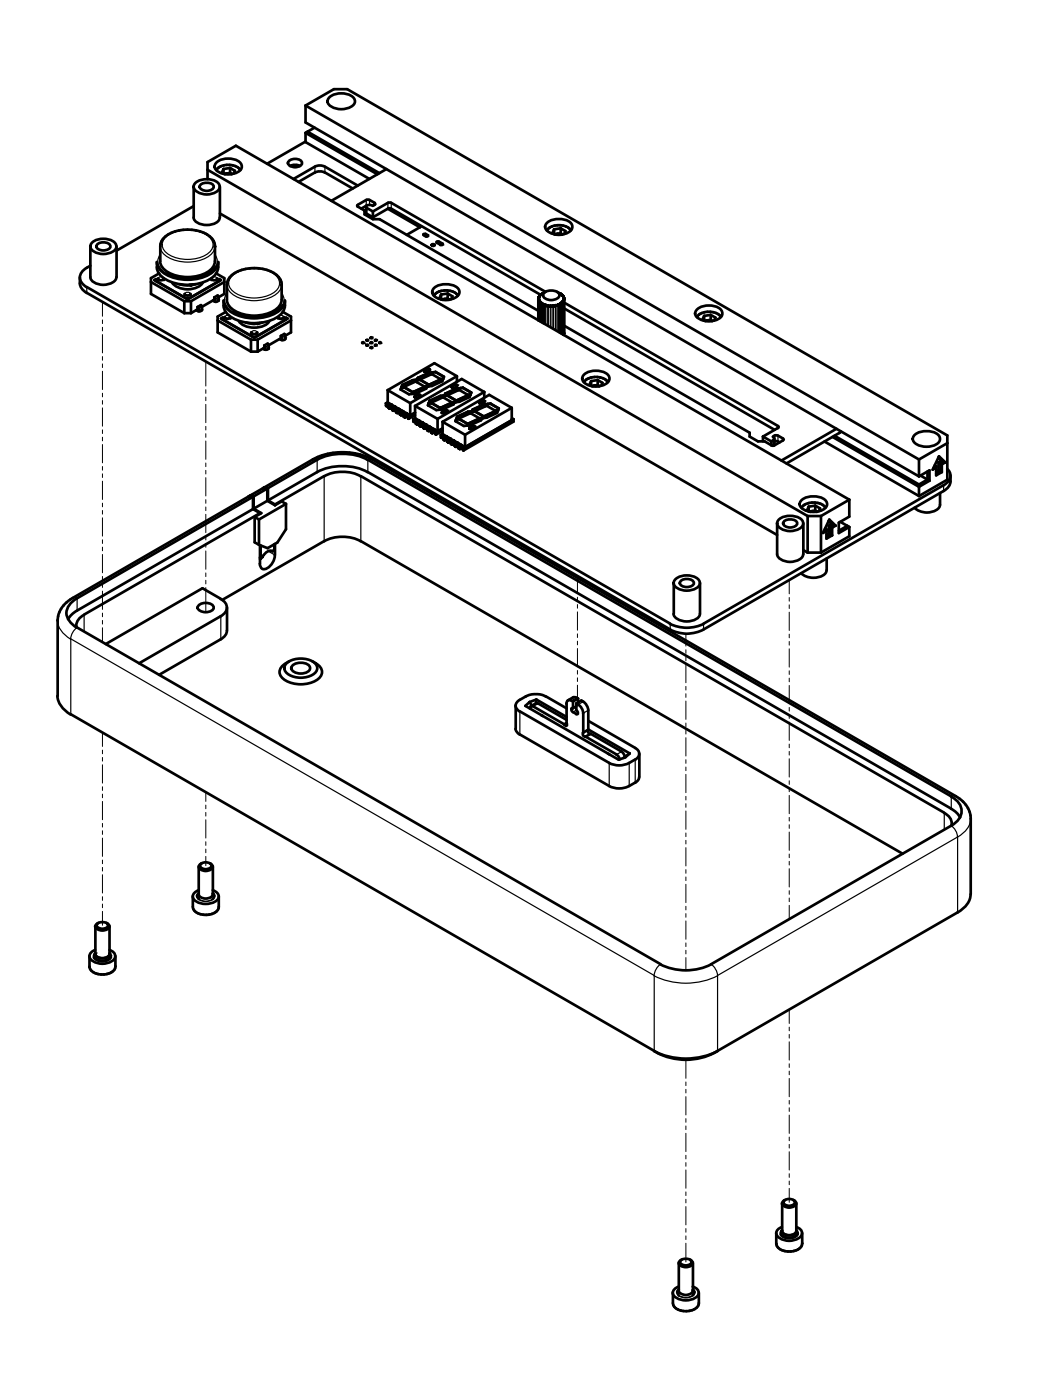
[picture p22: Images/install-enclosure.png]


## Install springs

**Springs are under tenstion - eye protection must be worn until completion of assembly**

1. Loop one end of a spring to the left carriage hook. This is easiest when approaching from above.
2. Draw slight tension into the spring and hook the other end onto the spring retainer.
3. There will be slight tension in the spring to keep it in position.

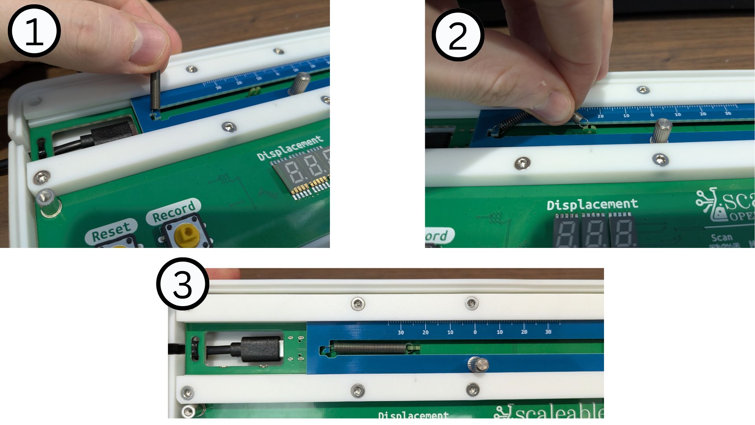
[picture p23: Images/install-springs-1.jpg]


Repeat the process with the second spring, at the second carriage hook.

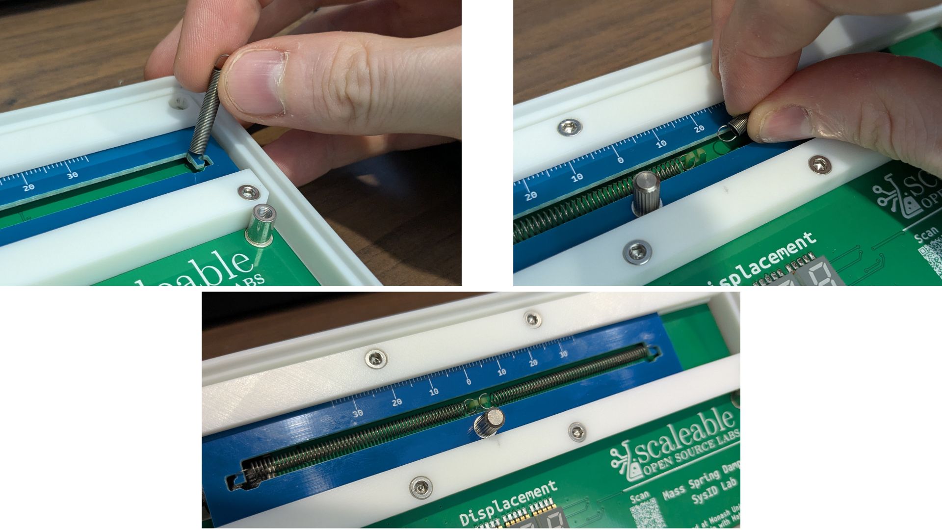
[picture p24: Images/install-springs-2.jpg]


## Install Coloured Button Caps

Push the coloured button caps onto the buttons - they will click into place.

- **Reset** button is White
- **Record** button is Red

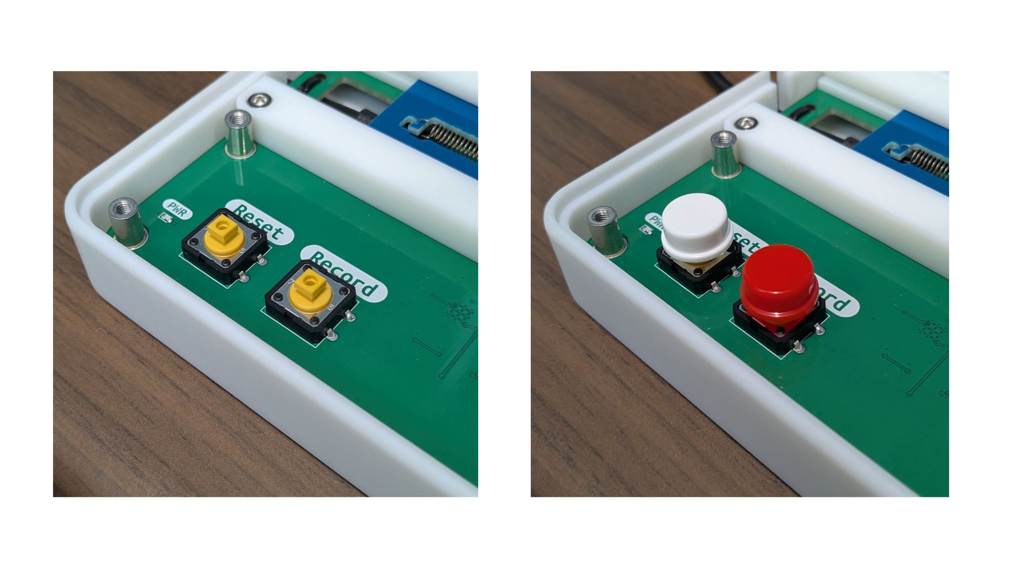
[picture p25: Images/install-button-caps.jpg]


## Mount Cable Blanking Plate and Lid

> **TODO:** install the 2x spacers here, just before the lid goes on. Needs proper step text and photos — see [`Enclosure/Spacer - FDM or Resin Print.stl`](<Enclosure/Spacer - FDM or Resin Print.stl>). Do not remove this note until the step below is written and the images are in place.

- Feed the cable blanking plate into position. It will be retained by the lid, once secured.
- Install the 2x spacers.
- Seat the lid into the enclosure, taking care to capture the cable blanking plate correctly.
- Fasten the lid with 2x long (M3x16mm) and 2x short (M3x8mm) screws
- Check the buttons clear the lid and their action is not impeded.

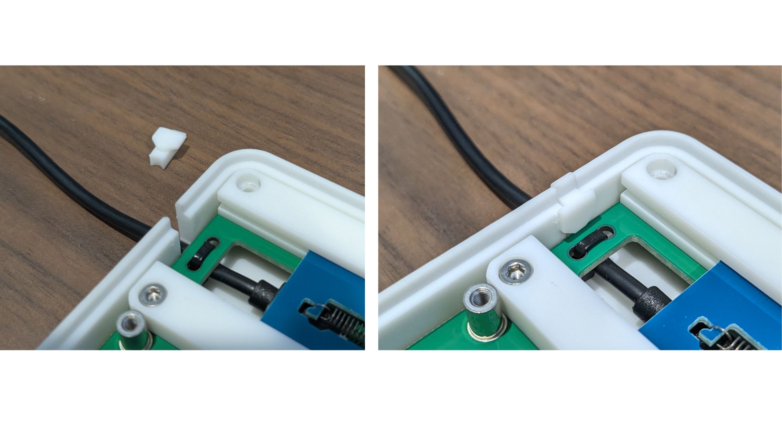
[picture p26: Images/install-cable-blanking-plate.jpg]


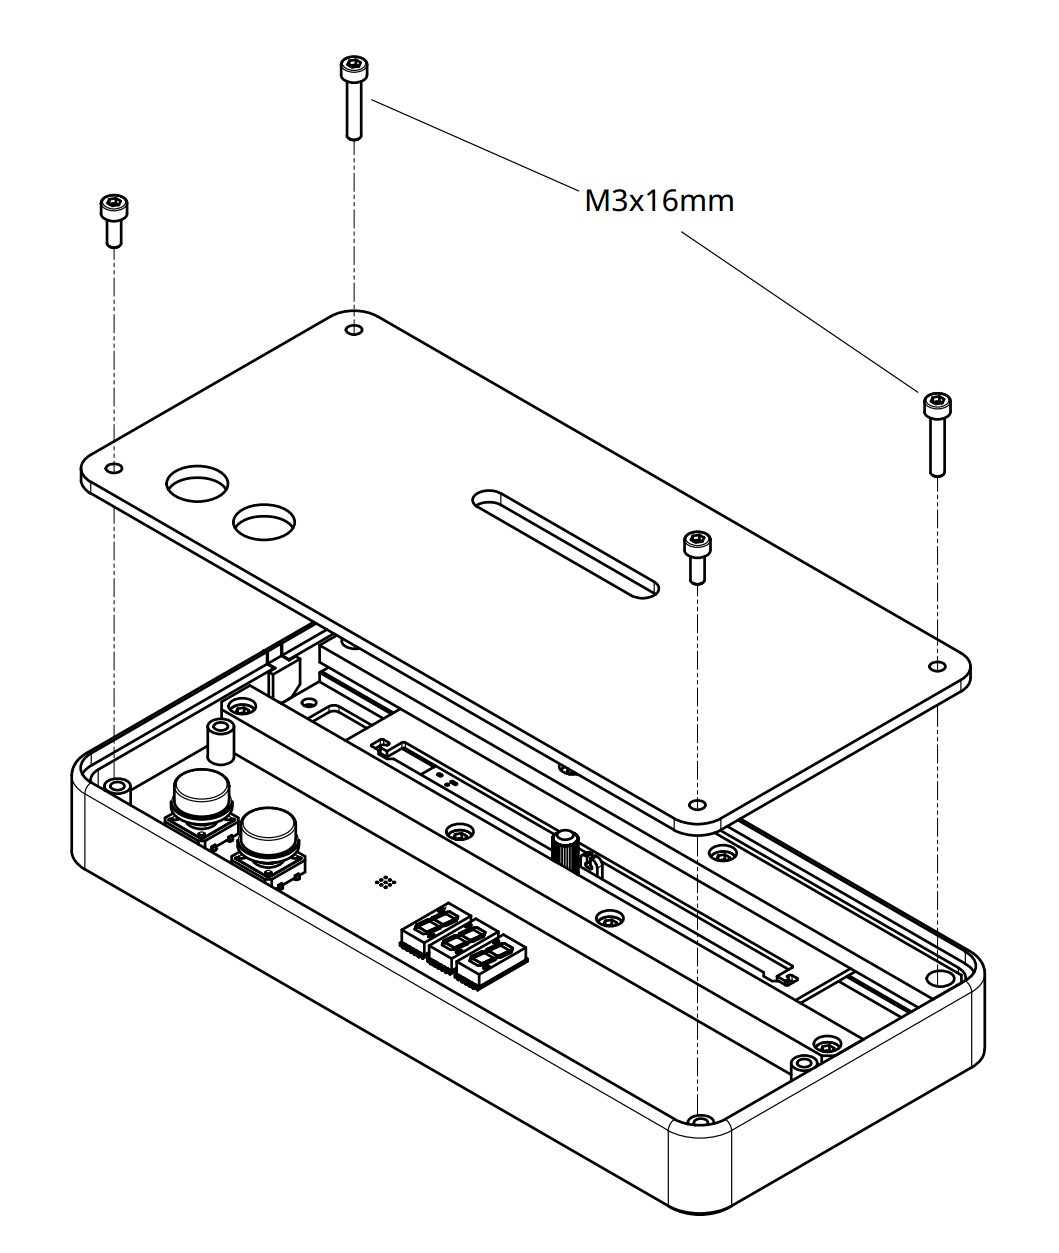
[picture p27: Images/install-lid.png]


## Conclusion

The mechanical assembly is complete. Check the carriage slides freely and returns near enough to centre to be satisfactory.



Proceed with the [Programming Instructions](Programming-Instructions.md)

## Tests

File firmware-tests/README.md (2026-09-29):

# Firmware host tests

These tests run on a PC, not the board. They compile the sketch's own `sweep.cpp`, `calibration.cpp` and `gpio.cpp`, plus the decoder copied out of the `.ino`, against small stand-ins for the Arduino API (`Arduino.h`, `EEPROM.h`).

Run them with bash and g++ (C++17):

```sh
./firmware-tests/run.sh
```

- **Output:** each test's summary and any failures. The script exits non-zero if anything fails.
- **Where files go:** the builds and the calibration test's full log go to `firmware-tests/build/`, which git ignores.
- **When to run them:** after any change to `sweep.cpp`, `calibration.cpp`, `gpio.cpp` or `processEncoderChange()`. If that function is renamed, `run.sh` stops with an error until the name in its awk line is updated.

## Calibration test (`calibration_test.cpp`)

A synthetic hand sweeps a synthetic encoder, and a copy of the test-mode loop reads it. The expected answers come from the physical model, never from the firmware's own maths.

- **The model:**
  - 3 mm bars at a 6 mm pitch, and a blurred light spot;
  - a phototransistor on a 10k pull-up that clips when it saturates;
  - comparators whose hysteresis and offsets differ from nominal.
- **The hand and loop:**
  - smooth passes with a wobble, and pauses;
  - loop jitter, with ADC reads trailing the pin read;
  - timestamps near the 32-bit wrap.
- **Checks:**
  - measured switching points and state widths against the model;
  - the half-duty threshold giving 3 mm of light in every 6 mm;
  - suggested thresholds against a grid search for the true best spacing;
  - the switching-point fallbacks;
  - `calibrateFromSweep()` saving, and refusing short sweeps, weak sensors and misplaced sensors.
- **Scenarios:**
  - the old midpoint thresholds;
  - deep clipping, and unclipped sensors;
  - slow, jerky and fast sweeps, and a long one;
  - mixed sensor strengths;
  - board 1, fitted to its sweeps of 2026-09-28.

## Decoder test (`decoder_test.cpp`)

Feeds pin states to the sketch's real `processEncoderChange()`:
- single steps;
- skipped states and crossed edges, which should count as ±2;
- jumps to the opposite state, whose counts should be lost;
- 2000 random walks, where the count must follow the true position.

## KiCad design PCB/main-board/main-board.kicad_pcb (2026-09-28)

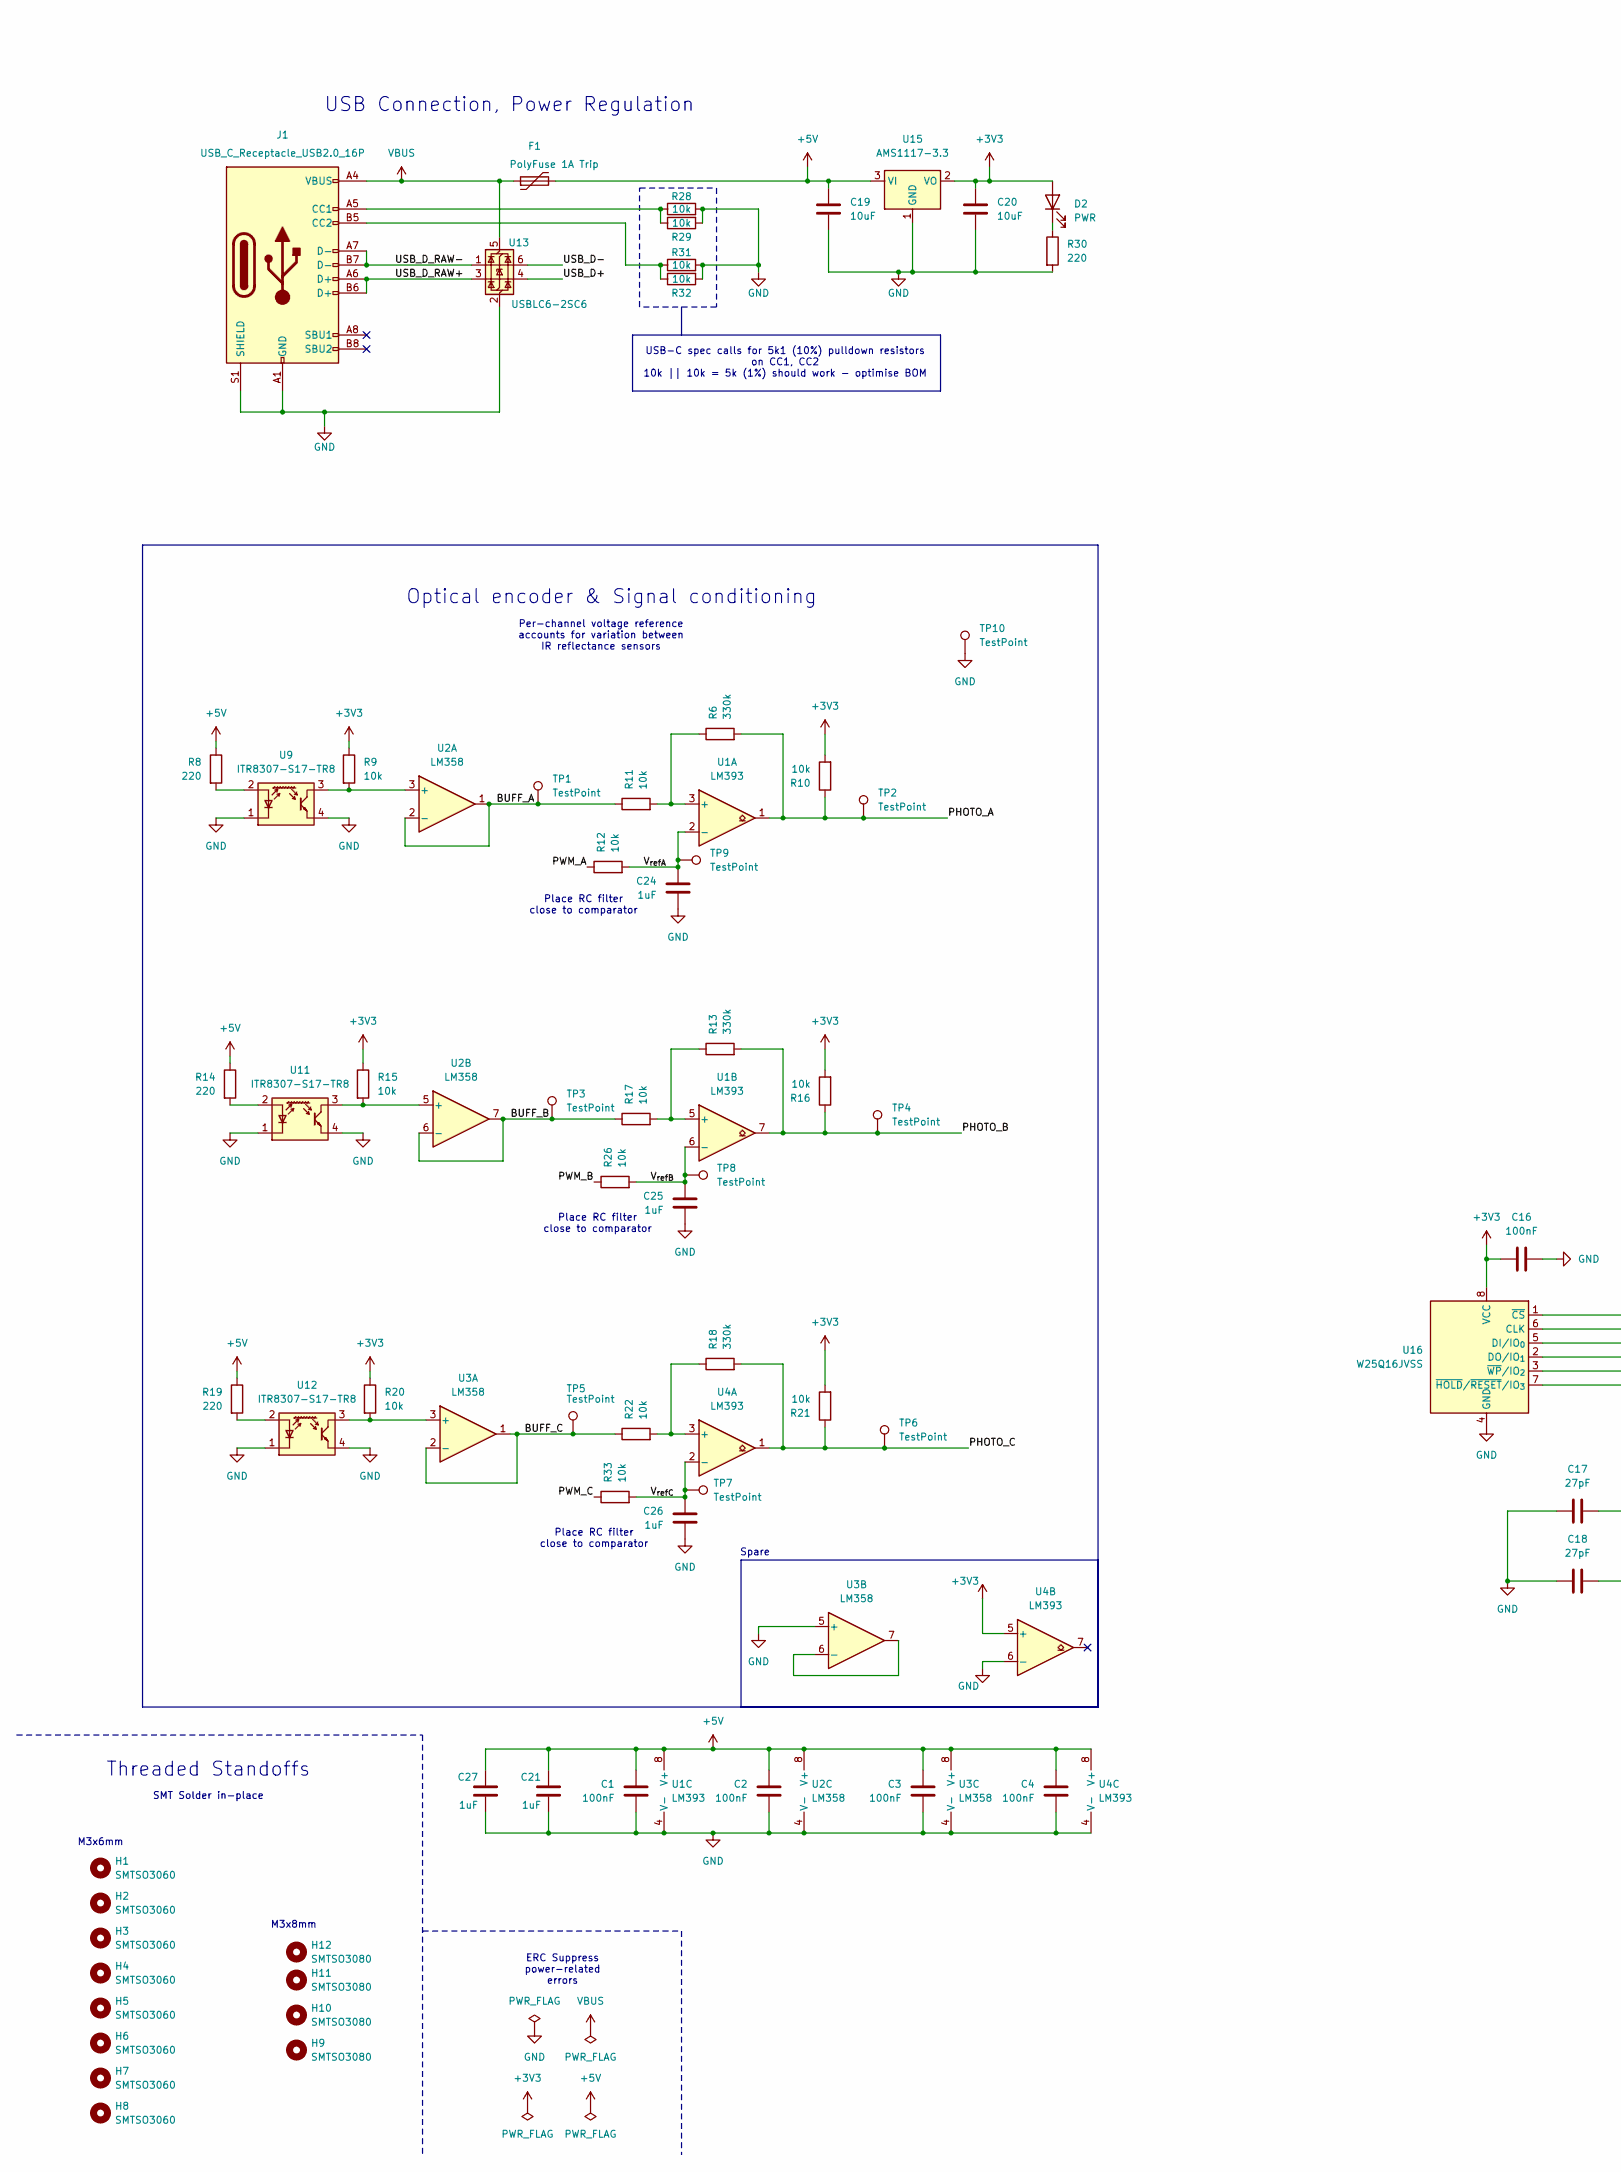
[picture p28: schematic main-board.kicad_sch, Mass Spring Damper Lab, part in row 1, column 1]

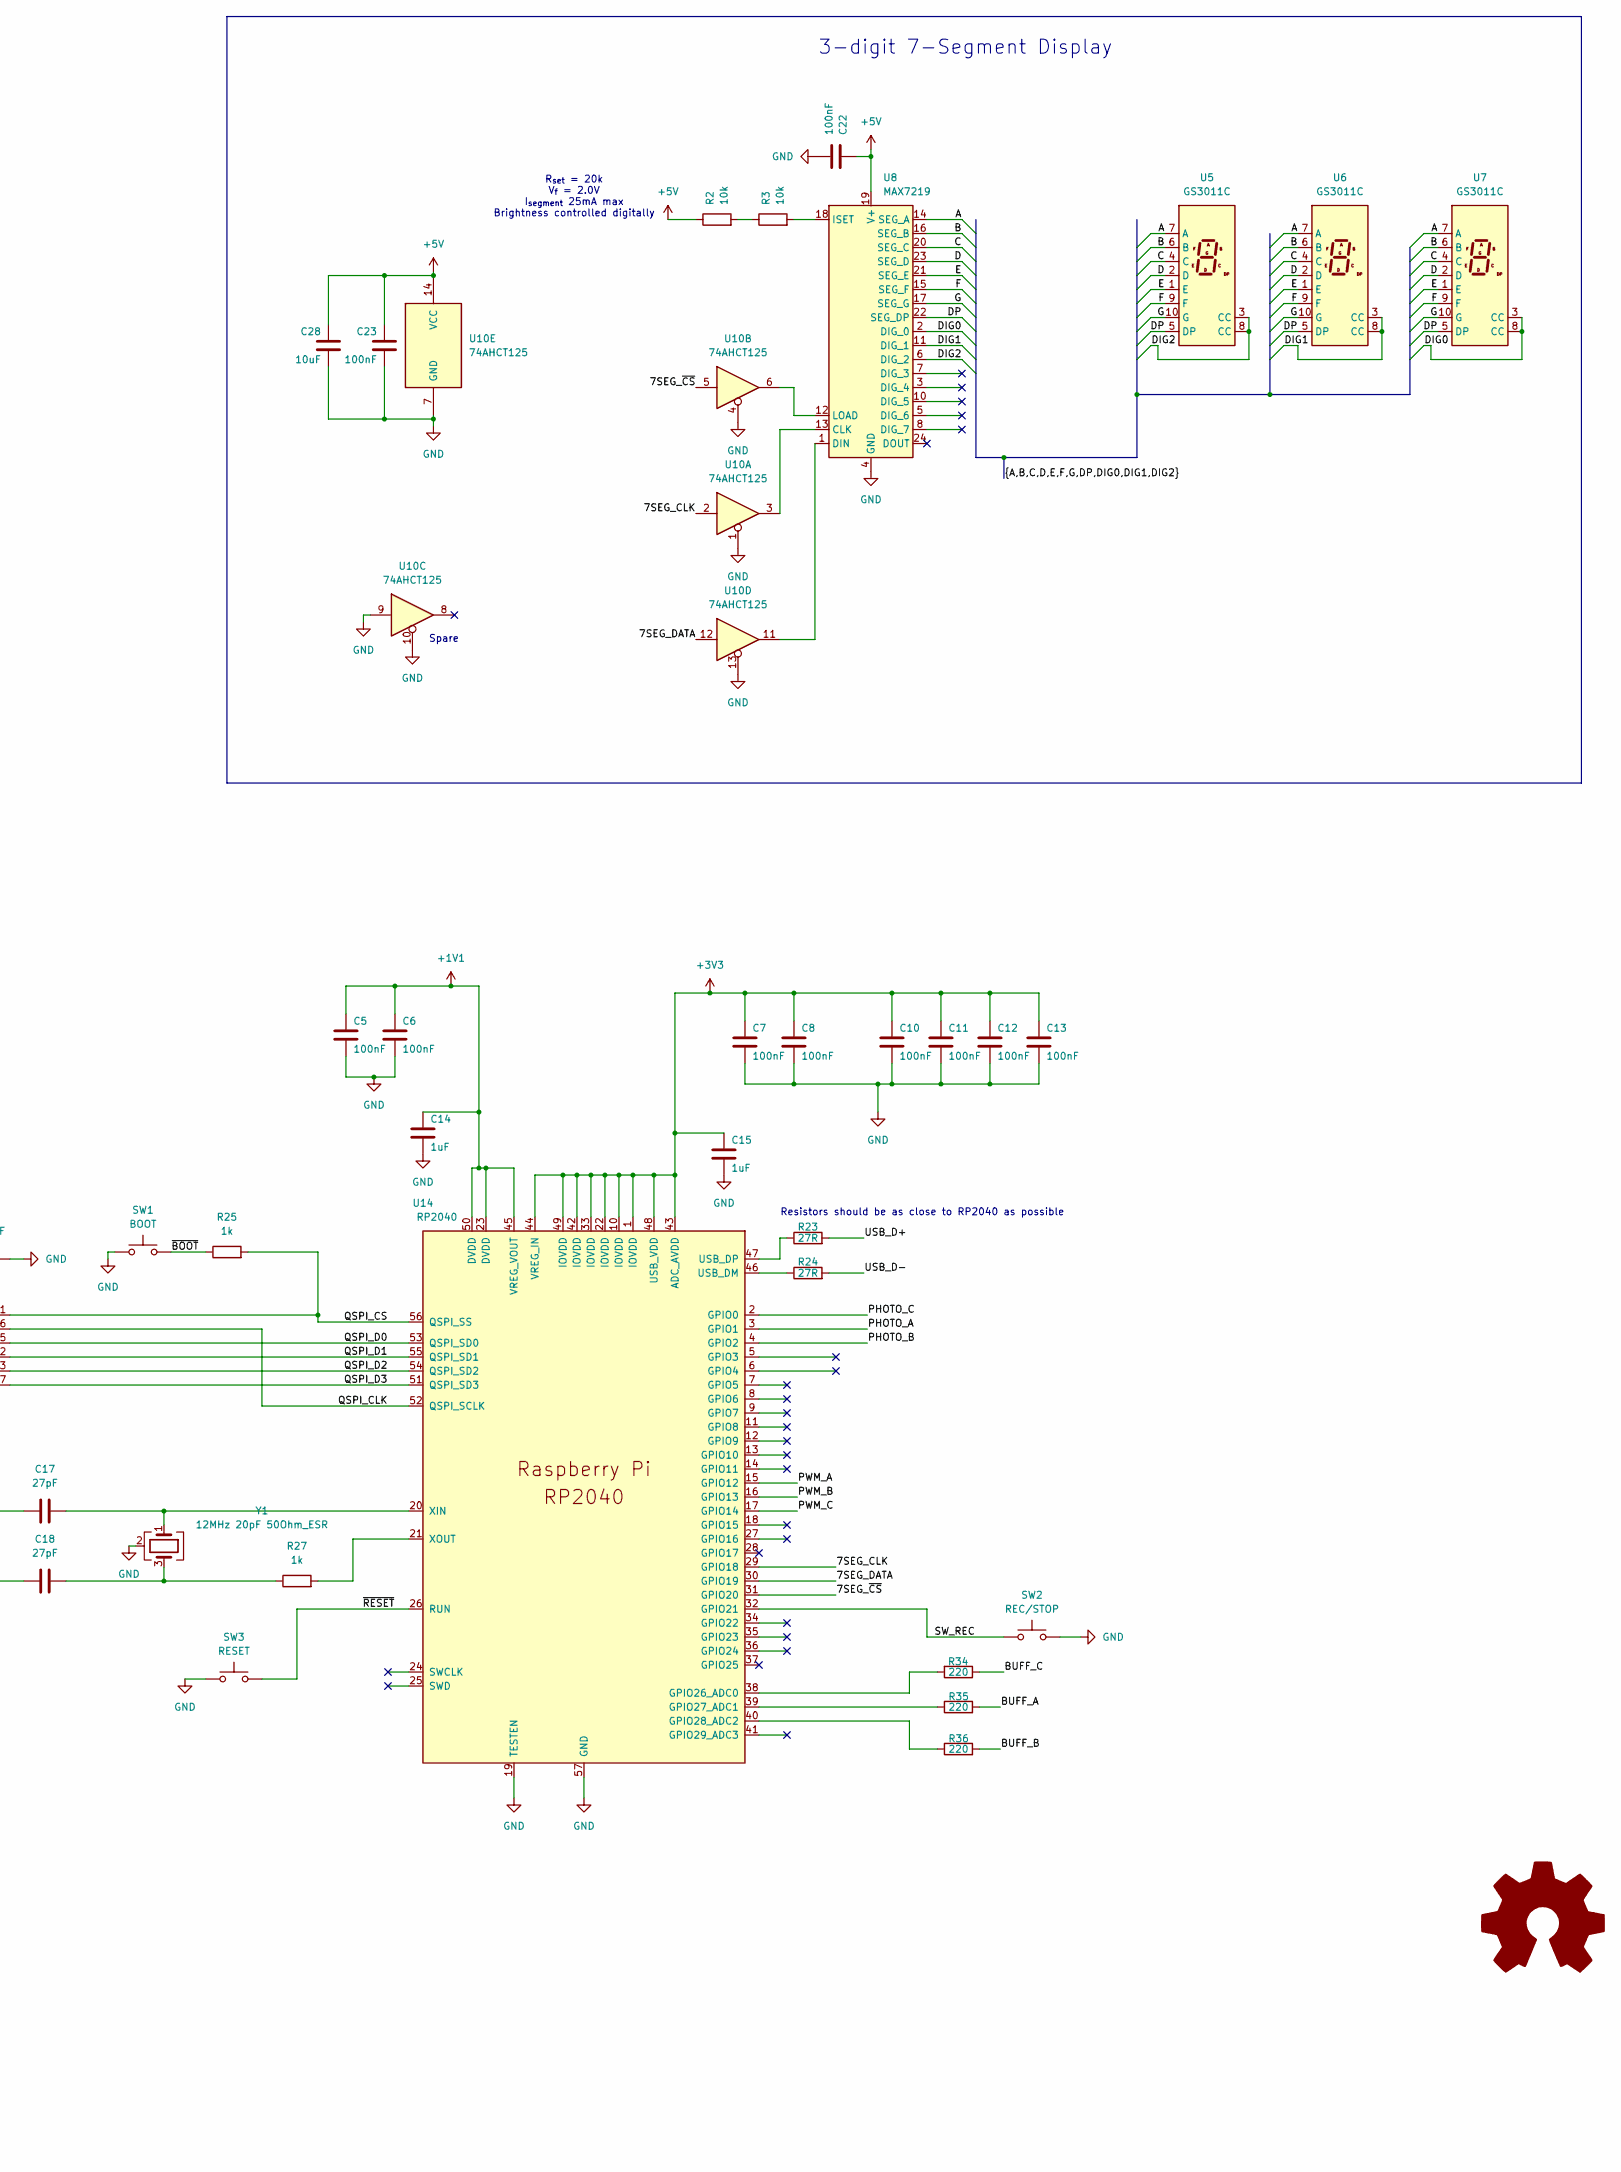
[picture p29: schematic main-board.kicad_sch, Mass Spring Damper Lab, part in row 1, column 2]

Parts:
C1, C2, C3, C4, C5, C6, C7, C8, C10, C11, C12, C13, C16, C22, C23: 100nF; C_0603_1608Metric; LCSC Part # C14663
C14, C15, C21, C24, C25, C26, C27: 1uF; C_0603_1608Metric; LCSC Part # C15849
C17, C18: 27pF; C_0603_1608Metric; LCSC Part # C1656
C19, C20, C28: 10uF; C_0603_1608Metric; LCSC Part # C19702
D2: PWR; LED_0603_1608Metric; LCSC Part # C965807
F1: PolyFuse 1A Trip; R_1206_3216Metric; LCSC Part # C720075
H1, H2, H3, H4, H5, H6, H7, H8: SMTSO3060; MountingHole_SMTSO3060_3.2mm_M3; LCSC Part # C2915637
H9, H10, H11, H12: SMTSO3080; MountingHole_SMTSO3080_3.2mm_M3; LCSC Part # C2916369
J1: USB_C_Receptacle_USB2.0_16P; USB_C_Receptacle_HCTL_HC-TYPE-C-16P-01A; LCSC Part # C2894897
R2, R3, R9, R10, R11, R12, R15, R16, R17, R20, R21, R22, R26, R28, R29, R31, R32, R33: 10k; R_0603_1608Metric; LCSC Part # C25804
R6, R13, R18: 330k; R_0603_1608Metric; LCSC Part # C23137
R8, R14, R19, R30, R34, R35, R36: 220; R_0603_1608Metric; LCSC Part # C22962
R23, R24: 27R; R_0603_1608Metric; LCSC Part # C25190
R25, R27: 1k; R_0603_1608Metric; LCSC Part # C21190
SW1: BOOT; SW_Push_1P1T_NO_E-Switch_TL3301NxxxxxG; LCSC Part # C455109
SW2: REC/STOP; SW_SPST_Omron_B3F-40xx; LCSC Part # C84931
SW3: RESET; SW_SPST_Omron_B3F-40xx; LCSC Part # C84931
TP1, TP2, TP3, TP4, TP5, TP6, TP7, TP8, TP9, TP10: TestPoint; TestPoint_Pad_D1.5mm
U1, U4: LM393; SOIC-8_3.9x4.9mm_P1.27mm; LCSC Part # C32901
U2, U3: LM358; SOIC-8_3.9x4.9mm_P1.27mm; LCSC Part # C9418
U5, U6, U7: GS3011C; GS3011; LCSC Part # C22462660
U8: MAX7219; SOIC-24W_7.5x15.4mm_P1.27mm; LCSC Part # C49443603
U9, U11, U12: ITR8307-S17-TR8; Everlight_ITR1201SR10AR; LCSC Part # C81632
U10: 74AHCT125; SOIC-14_3.9x8.7mm_P1.27mm; LCSC Part # C5962
U13: USBLC6-2SC6; SOT-23-6; LCSC Part # C2687116
U14: RP2040; RP2040-QFN-56; PARTREV 1.6.1; LCSC Part # C2040
U15: AMS1117-3.3; SOT-223-3_TabPin2; LCSC Part # C6186
U16: W25Q16JVSS; SOIC-8_5.3x5.3mm_P1.27mm; LCSC Part # C82317
Y1: 12MHz 20pF 50Ohm_ESR; Crystal_SMD_3225-4Pin_3.2x2.5mm; LCSC Part # C133334

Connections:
+1V1: C5.1, C6.1, C14.1, U14.23 (DVDD), U14.45 (VREG_VOUT), U14.50 (DVDD)
+3V3: C7.1, C8.1, C10.1, C11.1, C12.1, C13.1, C15.1, C16.1, C20.1, D2.2 (A), R9.1, R10.2, R15.1, R16.2, R20.1, R21.2, U4.5 (+), U14.1 (IOVDD), U14.10 (IOVDD), U14.22 (IOVDD), U14.33 (IOVDD), U14.42 (IOVDD), U14.43 (ADC_AVDD), U14.44 (VREG_IN), U14.48 (USB_VDD), U14.49 (IOVDD), U15.2 (VO), U16.8 (VCC)
+5V: C1.1, C2.1, C3.1, C4.1, C19.1, C21.1, C22.1, C23.1, C27.1, C28.1, F1.2, R2.1, R8.1, R14.1, R19.1, U1.8 (V+), U2.8 (V+), U3.8 (V+), U4.8 (V+), U8.19 (V+), U10.14 (VCC), U15.3 (VI)
/7SEG_CLK: U10.2, U14.29 (GPIO18)
/7SEG_DATA: U10.12, U14.30 (GPIO19)
/7SEG_~CS: U10.5, U14.31 (GPIO20)
/A: U5.7 (A), U6.7 (A), U7.7 (A), U8.14 (SEG_A)
/B: U5.6 (B), U6.6 (B), U7.6 (B), U8.16 (SEG_B)
/BUFF_A: R11.1, R35.2, TP1.1 (1_1), U2.1, U2.2 (-)
/BUFF_B: R17.1, R36.2, TP3.1 (1_1), U2.6 (-), U2.7
/BUFF_C: R22.1, R34.1, TP5.1 (1_1), U3.1, U3.2 (-)
/C: U5.4 (C), U6.4 (C), U7.4 (C), U8.20 (SEG_C)
/D: U5.2 (D), U6.2 (D), U7.2 (D), U8.23 (SEG_D)
/DIG0: U7.3 (CC), U7.8 (CC), U8.2 (DIG_0)
/DIG1: U6.3 (CC), U6.8 (CC), U8.11 (DIG_1)
/DIG2: U5.3 (CC), U5.8 (CC), U8.6 (DIG_2)
/DP: U5.5 (DP), U6.5 (DP), U7.5 (DP), U8.22 (SEG_DP)
/E: U5.1 (E), U6.1 (E), U7.1 (E), U8.21 (SEG_E)
/F: U5.9 (F), U6.9 (F), U7.9 (F), U8.15 (SEG_F)
/G: U5.10 (G), U6.10 (G), U7.10 (G), U8.17 (SEG_G)
/PHOTO_A: R6.2, R10.1, TP2.1 (1_1), U1.1, U14.3 (GPIO1)
/PHOTO_B: R13.2, R16.1, TP4.1 (1_1), U1.7, U14.4 (GPIO2)
/PHOTO_C: R18.2, R21.1, TP6.1 (1_1), U4.1, U14.2 (GPIO0)
/PWM_A: R12.1, U14.15 (GPIO12)
/PWM_B: R26.1, U14.16 (GPIO13)
/PWM_C: R33.1, U14.17 (GPIO14)
/QSPI_CLK: U14.52 (QSPI_SCLK), U16.6 (CLK)
/QSPI_CS: R25.2, U14.56 (QSPI_SS), U16.1 (~CS)
/QSPI_D0: U14.53 (QSPI_SD0), U16.5 (DI/IO_{0})
/QSPI_D1: U14.55 (QSPI_SD1), U16.2 (DO/IO_{1})
/QSPI_D2: U14.54 (QSPI_SD2), U16.3 (~WP/IO_{2})
/QSPI_D3: U14.51 (QSPI_SD3), U16.7 (~HOLD/~RESET/IO_{3})
/SW_REC: SW2.1, U14.32 (GPIO21)
/USB_D+: R23.2, U13.4 (I/O2)
/USB_D-: R24.2, U13.6 (I/O1)
/USB_D_RAW+: J1.A6 (D+), J1.B6 (D+), U13.3 (I/O2)
/USB_D_RAW-: J1.A7 (D-), J1.B7 (D-), U13.1 (I/O1)
/V_{refA}: C24.1, R12.2, TP9.1 (1_1), U1.2 (-)
/V_{refB}: C25.1, R26.2, TP8.1 (1_1), U1.6 (-)
/V_{refC}: C26.1, R33.2, TP7.1 (1_1), U4.2 (-)
/~BOOT: R25.1, SW1.1
/~RESET: SW3.1, U14.26 (RUN)
GND: C1.2, C2.2, C3.2, C4.2, C5.2, C6.2, C7.2, C8.2, C10.2, C11.2, C12.2, C13.2, C14.2, C15.2, C16.2, C17.1, C18.1, C19.2, C20.2, C21.2, C22.2, C23.2, C24.2, C25.2, C26.2, C27.2, C28.2, J1.A1 (GND), J1.A12 (GND), J1.B1 (GND), J1.B12 (GND), J1.S1 (SHIELD), R28.2, R29.2, R30.2, R31.2, R32.2, SW1.2, SW2.2, SW3.2, TP10.1 (1_1), U1.4 (V-), U2.4 (V-), U3.4 (V-), U3.5 (+), U4.4 (V-), U4.6 (-), U8.4 (GND), U8.9 (GND), U9.1 (K), U9.4, U10.1, U10.4, U10.7 (GND), U10.9, U10.10, U10.13, U11.1 (K), U11.4, U12.1 (K), U12.4, U13.2 (GND), U14.19 (TESTEN), U14.57 (GND), U15.1 (GND), U16.4 (GND), Y1.2 (G), Y1.4 (G)
unnamed: C18.2, R27.1, Y1.3
unnamed: D2.1 (K), R30.1
unnamed: J1.A5 (CC1), R28.1, R29.1
unnamed: J1.B5 (CC2), R31.1, R32.1
unnamed: R2.2, R3.1
unnamed: R6.1, R11.2, U1.3 (+)
unnamed: R13.1, R17.2, U1.5 (+)
unnamed: R9.2, U2.3 (+), U9.3
unnamed: R15.2, U2.5 (+), U11.3
unnamed: R20.2, U3.3 (+), U12.3
unnamed: U3.6 (-), U3.7
unnamed: R18.1, R22.2, U4.3 (+)
unnamed: U8.13 (CLK), U10.3
unnamed: U8.1 (DIN), U10.11
unnamed: R3.2, U8.18 (ISET)
unnamed: U8.12 (LOAD), U10.6
unnamed: R8.2, U9.2 (A)
unnamed: R14.2, U11.2 (A)
unnamed: R19.2, U12.2 (A)
unnamed: R34.2, U14.38 (GPIO26_ADC0)
unnamed: R35.1, U14.39 (GPIO27_ADC1)
unnamed: R36.1, U14.40 (GPIO28_ADC2)
unnamed: R24.1, U14.46 (USB_DM)
unnamed: R23.1, U14.47 (USB_DP)
unnamed: C17.2, U14.20 (XIN), Y1.1
unnamed: R27.2, U14.21 (XOUT)
VBUS: F1.1, J1.A4 (VBUS), J1.A9 (VBUS), J1.B4 (VBUS), J1.B9 (VBUS), U13.5 (VBUS)

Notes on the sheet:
USB-C spec calls for 5k1 (10%) pulldown resistors on CC1, CC2 10k || 10k = 5k (1%) should work - optimise BOM
Spare
M3x6mm
Place RC filter close to comparator
Resistors should be as close to RP2040 as possible
Per-channel voltage reference accounts for variation between IR reflectance sensors
3-digit 7-Segment Display
Threaded Standoffs
USB Connection, Power Regulation
ERC Suppress power-related errors
SMT Solder in-place
R_{set} = 20k V_{f} = 2.0V I_{segment} 25mA max Brightness controlled digitally
Optical encoder & Signal conditioning
M3x8mm

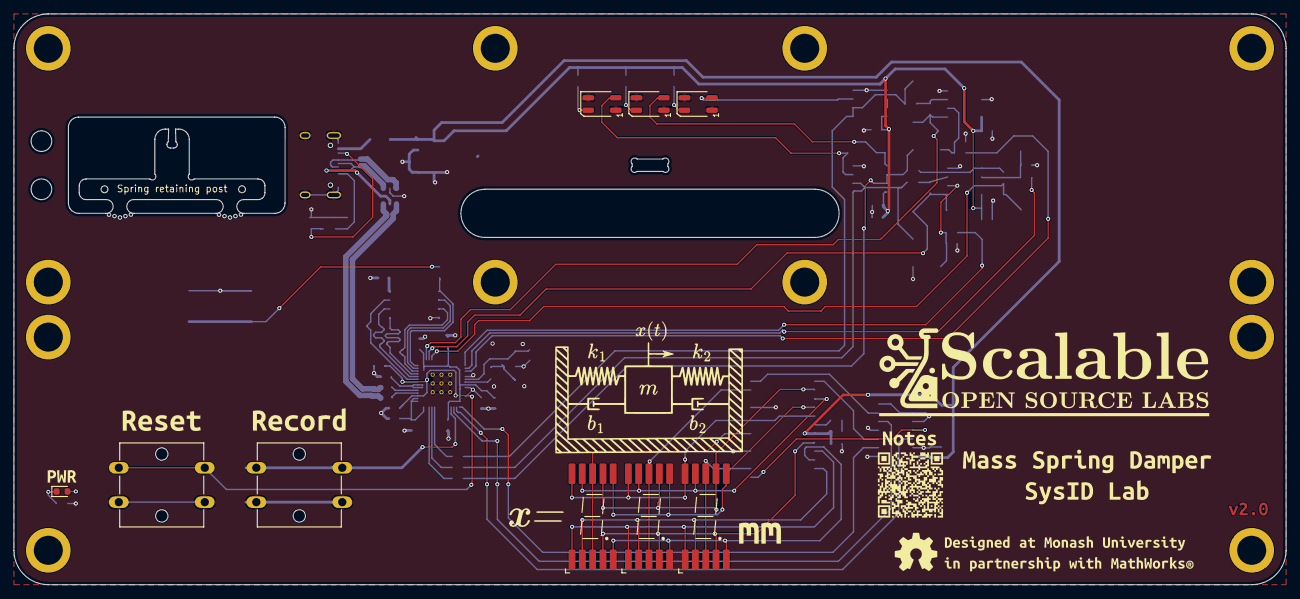
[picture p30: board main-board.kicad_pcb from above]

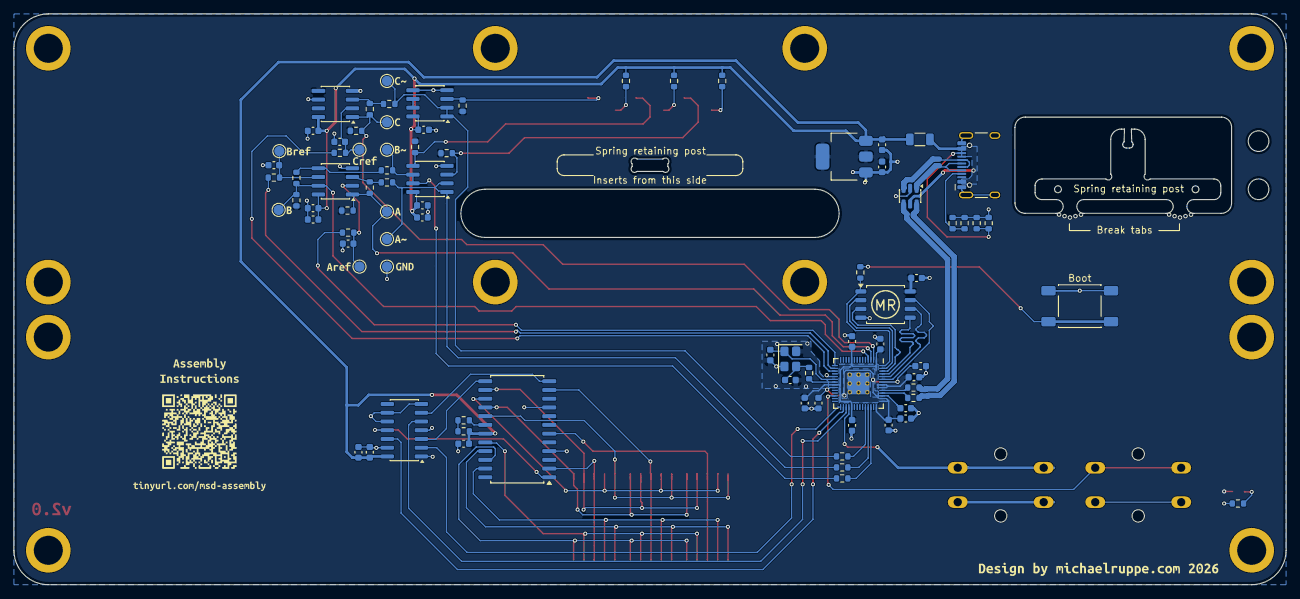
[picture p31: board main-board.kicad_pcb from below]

Board: 2 copper layers, 185.0 x 83.0 mm, 130 parts (105 on the bottom side), 70 nets.

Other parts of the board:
kibuzzard-6A5D9E3D: G***; kibuzzard-6A5D9E3D
kibuzzard-6A5DA214: G***; kibuzzard-6A5DA214
kibuzzard-6A5DFDED: G***; kibuzzard-6A5DFDED
kibuzzard-6A5DFE62: G***; kibuzzard-6A5DFE62
kibuzzard-6A9CABE9: G***; kibuzzard-6A9CABE9
kibuzzard-6A9CB9E8: G***; kibuzzard-6A9CB9E8
kibuzzard-6A9CBA3E: G***; kibuzzard-6A9CBA3E
kibuzzard-6A9CBA9F: G***; kibuzzard-6A9CBA9F
kibuzzard-6A9CBA16: G***; kibuzzard-6A9CBA16
kibuzzard-6A9CBA29: G***; kibuzzard-6A9CBA29
kibuzzard-6A9CBA31: G***; kibuzzard-6A9CBA31
kibuzzard-6A9CBA47: G***; kibuzzard-6A9CBA47
kibuzzard-6A9CBA92: G***; kibuzzard-6A9CBA92
kibuzzard-6A9CBA99: G***; kibuzzard-6A9CBA99
kibuzzard-6A9CBB45: G***; kibuzzard-6A9CBB45
kibuzzard-6A601CB9: G***; kibuzzard-6A601CB9
kibuzzard-6A601CBF: G***; kibuzzard-6A601CBF
kibuzzard-6A601CD4: G***; kibuzzard-6A601CD4
kibuzzard-6A815F94: G***; kibuzzard-6A815F94
kibuzzard-6930AF86: G***; kibuzzard-6930AF86
kibuzzard-69645CED: G***; kibuzzard-69645CED
kibuzzard-6978363D: G***; kibuzzard-6978363D
kibuzzard-69310180: G***; kibuzzard-69310180
kibuzzard-69783696: G***; kibuzzard-69783696
mousebite1, mousebite2: VAL**; mouse-bite-2mm-4mm-single-sided

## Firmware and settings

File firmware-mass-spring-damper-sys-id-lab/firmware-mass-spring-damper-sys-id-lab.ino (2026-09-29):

#define VERSION_MAJOR 2
#define VERSION_MINOR 0

// Create version string using preprocessor stringification
#define STRINGIFY(x) #x
#define TOSTRING(x) STRINGIFY(x)
#define VERSION_STRING TOSTRING(VERSION_MAJOR) "." TOSTRING(VERSION_MINOR)

#include <Arduino.h>
#include "Adafruit_TinyUSB.h"
#include "ramdisk.h"
#include "gpio.h"
#include "calibration.h"
#include "sweep.h"
#include "LedControlPatched.h"

// Function Prototypes (plays nice with VSCode IntelliSense, Arduino doesn't care)
static void writeToBlocks(const char* data, uint32_t len, uint32_t& current_block, uint32_t& block_offset);
void handleStandbyMode();
void handleCaptureMode();
void handleMountDriveMode();
void handleTestMode();
void printTestSummary();
void showTestMessage(const uint8_t word[3], unsigned long durationMs);
void handleSerialCommand();
void enableEncoderInterrupts();
void disableEncoderInterrupts();
void processEncoderChange();
int32_t msc_read_callback(uint32_t lba, void* buffer, uint32_t bufsize);
int32_t msc_write_callback(uint32_t lba, uint8_t* buffer, uint32_t bufsize);
void msc_flush_callback(void);
bool msc_start_stop_callback(uint8_t power_condition, bool start, bool load_eject);
bool msc_ready_callback(void);

LedControl lc = LedControl(19, 18, 20, 1);

#define CAPTURE_TIMEOUT_MS 5000  // maximum possible recording duration
#define MOTION_TIMEOUT_MS 500    // timeout when mass has stopped moving
#define USB_DETACH_DELAY_MS 10
#define SERIAL_WAIT_MS 100
#define POST_CAPTURE_DELAY_MS 1000
#define TEST_STREAM_MS 50        // Test mode: 20 Hz live stream for the Serial Plotter
#define BTN_DEBOUNCE_MS 30
#define CAL_HOLD_MS 2000         // Test mode: hold REC this long to calibrate
#define TEST_STATUS_MS 1500      // Test mode: how long "CAL"/"dEF" shows on entry
#define TEST_RESULT_MS 2000      // Test mode: how long "CAL"/"Err"/"dEF" shows after calibrating or clearing

// Volatile variables shared between ISR and main loop
volatile bool stateChanged = false;
volatile int positionCounter = 0;

// State tracking
uint8_t currentState = 0;
uint8_t previousState = 0;        // The last valid state: 010 and 101 are never kept
unsigned int recoveredSkips = 0;  // Two-state jumps counted as +-2: a state the loop missed, or two edges that crossed
unsigned int lostCounts = 0;      // Jumps to the opposite state, whose direction is unknown, so their count is lost

unsigned long timestamp = 0;
bool testStream = true;  // Test mode live stream, toggled with the S command
unsigned long testMessageMs = 0;          // When the current test-mode status word went up
unsigned long testMessageDurationMs = 0;  // How long it stays before the channel mirror resumes

// Test-mode status words as raw 7-seg segment bytes, left to right
const uint8_t WORD_CAL[3] = { 0x4E, 0x77, 0x0E };  // "CAL": running this unit's saved thresholds
const uint8_t WORD_DEF[3] = { 0x3D, 0x4F, 0x47 };  // "dEF": no saved calibration, running the defaults
const uint8_t WORD_ERR[3] = { 0x4F, 0x05, 0x05 };  // "Err": calibration refused, nothing saved

Adafruit_USBD_MSC usb_msc;

// Data collection structure
#define MAX_DATAPOINTS 5000
struct DataPoint {
  uint32_t millisecond;
  int displacement_mm;
};

DataPoint timeseries[MAX_DATAPOINTS];
int datapoint_count = 0;

// Function to add datapoint
void addDataPoint(uint32_t ms, int disp) {
  if (datapoint_count < MAX_DATAPOINTS) {
    timeseries[datapoint_count].millisecond = ms;
    timeseries[datapoint_count].displacement_mm = disp;
    datapoint_count++;
  }
}


// Generate CSV content from timeseries data
void generateCSV() {
  uint32_t current_block = 4;  // Data blocks start at block 4 (Block0: Boot, Block1: FAT1, Block2: FAT2, Block3: Root Dir)
  uint32_t block_offset = 0;
  char line_buffer[32];  // Single line buffer. The header needs 29 bytes, the longest possible data row 24.

  // Write header
  uint32_t len = sprintf(line_buffer, "Time [us],Displacement [mm]\n");
  writeToBlocks(line_buffer, len, current_block, block_offset);

  // Write data rows, stopping at the last whole row that fits on the disk
  for (int i = 0; i < datapoint_count; i++) {
    len = sprintf(line_buffer, "%lu,%d\n",
                  timeseries[i].millisecond,
                  timeseries[i].displacement_mm);
    if (current_block * DISK_BLOCK_SIZE + block_offset + len > DISK_BLOCK_NUM * DISK_BLOCK_SIZE) {
      Serial.printf("CSV truncated at %d of %d rows (drive full)\n", i, datapoint_count);
      break;
    }
    writeToBlocks(line_buffer, len, current_block, block_offset);
  }

  // Calculate file metrics
  uint32_t file_size = (current_block - 4) * DISK_BLOCK_SIZE + block_offset;
  uint32_t blocks_needed = current_block - 4 + (block_offset > 0 ? 1 : 0);

  // Zero remainder of final block. Partial blocks must be zeroed to avoid garbage data.
  if (block_offset > 0) {
    memset(msc_disk[current_block] + block_offset, 0, DISK_BLOCK_SIZE - block_offset);
  }

  // Update BOTH FAT Tables (Windows requires both copies to match)
  for (int fat_copy = 0; fat_copy < 2; fat_copy++) {
    uint8_t* fat = msc_disk[1 + fat_copy];  // Block 1 (FAT1) and Block 2 (FAT2)

    // Chain logic:
    // if not last block: next_cluster = cluster + 1 (points to next block)
    // if last block: next_cluster = 0xFFF (EOF marker)
    for (uint32_t cluster = 2; cluster < 2 + blocks_needed; cluster++) {
      uint16_t next_cluster = (cluster < 2 + blocks_needed - 1) ? (cluster + 1) : 0xFFF;
      uint32_t byte_offset = (cluster * 3) / 2;

      // FAT12 Packing (12 bits per entry). Two entries = 3 bytes.
      if (cluster % 2 == 0) {
        fat[byte_offset] = next_cluster & 0xFF;
        fat[byte_offset + 1] = (fat[byte_offset + 1] & 0xF0) | ((next_cluster >> 8) & 0x0F);
      } else {
        fat[byte_offset] = (fat[byte_offset] & 0x0F) | ((next_cluster << 4) & 0xF0);
        fat[byte_offset + 1] = (next_cluster >> 4) & 0xFF;
      }
    }
  }

// Update Block3 directory entry
// Block3, starting byte 32 defines Data_.csv
// Bytes 37-39: Characters 6-8 of filename (Data_###) - generate three random alphanumeric characters to append to this file (helps avoid file-overwrites when user copies data onto PC)
// Bytes 60-63: 4-bytes little-endian file size
#define ROOT_DIR_BLOCK 3
#define FILENAME_RANDOM_OFFSET 37  // Start of the 3 spaces in "DATA_   "
#define FILE_SIZE_OFFSET 60

  // Generate 3 random alphanumeric characters
  const char charset[] = "ABCDEFGHIJKLMNOPQRSTUVWXYZ0123456789";
  const int charset_size = sizeof(charset) - 1;  // Exclude null terminator
  randomSeed(micros());
  for (int i = 0; i < 3; i++) {
    msc_disk[ROOT_DIR_BLOCK][FILENAME_RANDOM_OFFSET + i] = charset[random(charset_size)];
  }

  // Update file size
  msc_disk[ROOT_DIR_BLOCK][FILE_SIZE_OFFSET] = file_size & 0xFF;
  msc_disk[ROOT_DIR_BLOCK][FILE_SIZE_OFFSET + 1] = (file_size >> 8) & 0xFF;
  msc_disk[ROOT_DIR_BLOCK][FILE_SIZE_OFFSET + 2] = (file_size >> 16) & 0xFF;
  msc_disk[ROOT_DIR_BLOCK][FILE_SIZE_OFFSET + 3] = (file_size >> 24) & 0xFF;
}

static void writeToBlocks(const char* data, uint32_t len,
                          uint32_t& current_block, uint32_t& block_offset) {
  for (uint32_t i = 0; i < len; i++) {
    msc_disk[current_block][block_offset++] = data[i];
    if (block_offset >= DISK_BLOCK_SIZE) {
      current_block++;
      block_offset = 0;
    }
  }
}

void updateBootSectorForDiskSize() {
  // Update total sectors in boot sector (bytes 19-20)
  msc_disk[0][19] = DISK_BLOCK_NUM & 0xFF;
  msc_disk[0][20] = (DISK_BLOCK_NUM >> 8) & 0xFF;

  // Calculate required FAT size (12 bits per entry, 8 entries per 3 bytes)
  uint32_t fat_entries = DISK_BLOCK_NUM + 2;  // +2 for reserved entries
  uint32_t fat_bytes = (fat_entries * 3 + 1) / 2;
  uint32_t sectors_per_fat = (fat_bytes + DISK_BLOCK_SIZE - 1) / DISK_BLOCK_SIZE;

  // Update sectors per FAT (bytes 22-23)
  msc_disk[0][22] = sectors_per_fat & 0xFF;
  msc_disk[0][23] = (sectors_per_fat >> 8) & 0xFF;
}


enum modes {
  INITIALISED,
  STANDBY,
  CAPTURE,
  MOUNT_DRIVE,
  TEST
};
modes mode = STANDBY;
modes last_mode = INITIALISED;

// the setup function runs once when you press reset or power the board
void setup() {
  // Manual begin() is required on core without built-in support e.g. mbed rp2040
  if (!TinyUSBDevice.isInitialized()) {
    TinyUSBDevice.begin(0);
  }

  Serial.begin(115200);
  static uint8_t serial_initialiser_counter = 0;
  while (!Serial && serial_initialiser_counter < 5) {
    delay(100);
    serial_initialiser_counter++;
  }

  gpio_initialise();
  Serial.printf("# fw=%s VrefA=%u VrefB=%u VrefC=%u mV cal=%s\n", VERSION_STRING, getVref(CH_A), getVref(CH_B),
                getVref(CH_C), isCalibrated() ? "yes" : "no");

  // Enter test mode if record button is held down at power-up/reset
  if (digitalRead(btnRec) == 0) mode = TEST;

  // Set disk vendor id, product id and revision with string up to 8, 16, 4 characters respectively
  usb_msc.setID("DntPanic", "Mass Storage", VERSION_STRING);

  // Set disk size
  usb_msc.setCapacity(DISK_BLOCK_NUM, DISK_BLOCK_SIZE);
  updateBootSectorForDiskSize();
  // Set callback
  usb_msc.setReadWriteCallback(msc_read_callback, msc_write_callback, msc_flush_callback);
  usb_msc.setStartStopCallback(msc_start_stop_callback);
  usb_msc.setReadyCallback(msc_ready_callback);

  // Set Lun ready (RAM disk is always ready)
  usb_msc.setUnitReady(true);

  // 7-segment display
  lc.shutdown(0, false);  // wakeup
  lc.setIntensity(0, 15);  // max brightness (0 to 15)
  lc.clearDisplay(0);

}



void loop() {
  switch (mode) {
    case STANDBY:
      handleStandbyMode();
      break;
    case CAPTURE:
      handleCaptureMode();
      break;
    case MOUNT_DRIVE:
      handleMountDriveMode();
      break;
    case TEST:
      handleTestMode();
      break;
  }
}


void handleStandbyMode() {
  if (mode != last_mode) {
    Serial.println("Standing By");

    enableEncoderInterrupts();


    last_mode = mode;

    // throw away first reading - zeros the device and updates encoder-last-state
    processEncoderChange();
    positionCounter = 0;
  }
  if (digitalRead(btnRec) == 0) mode = CAPTURE;

  // Display live displacement
  processEncoderChange();
  long units = abs(positionCounter) % 10;
  long tens = (abs(positionCounter) / 10) % 10;
  lc.setDigit(0, 0, units, false);
  if (tens != 0) lc.setDigit(0, 1, tens, false);
  else lc.setChar(0, 1, ' ', false);

  if (positionCounter < 0) lc.setChar(0, 2, '-', false);
  else lc.setChar(0, 2, ' ', false);
}

void handleCaptureMode() {
  static unsigned long time_begin;
  static unsigned int num_points = 0;

  // Mode entry
  if (mode != last_mode) {
    Serial.println("Capturing");
    digitalWrite(ledRec, HIGH);

    // display "rEC" (recording)
    lc.setRow(0, 2, 0x05);         // r
    lc.setChar(0, 1, 'E', false);  // E
    lc.setRow(0, 0, 0x4E);         // c
    last_mode = mode;

    stateChanged = false;
    recoveredSkips = 0;
    lostCounts = 0;
    time_begin = micros();
  }
  static unsigned long lastMotion = 0;
  // Process state changes
  if (stateChanged) {
    num_points++;

    stateChanged = false;
    processEncoderChange();
    if (num_points == 1) time_begin = timestamp;  // first timestamp starts at zero

    lastMotion = millis();

    if (num_points > MAX_DATAPOINTS) {
      mode = MOUNT_DRIVE;
      return;
    }

    addDataPoint(timestamp - time_begin, positionCounter);
    Serial.printf("%8d, %4d\n", timestamp, positionCounter);
  }


  // Timeout check

  bool motionTimeout = (millis() - lastMotion > MOTION_TIMEOUT_MS) && num_points > 100;

  if (micros() - time_begin > 1000 * CAPTURE_TIMEOUT_MS || motionTimeout) {
    disableEncoderInterrupts();
    Serial.printf("Done, %u skipped states recovered, %u counts lost\n", recoveredSkips, lostCounts);
    digitalWrite(ledRec, LOW);
    mode = MOUNT_DRIVE;
  }
}

void handleMountDriveMode() {
  if (mode != last_mode) {
    last_mode = MOUNT_DRIVE;

    // Display 'U.S.b.' on 7-seg with decimal points
    lc.setRow(0, 2, 0x3E | 0x80);         // U.
    lc.setDigit(0, 1, 5, true);           // S.
    lc.setChar(0, 0, 'b', true);          // b.

    generateCSV();
    usb_msc.begin();

    if (TinyUSBDevice.mounted()) {
      TinyUSBDevice.detach();
      delay(1000);  // Longer delay for Windows to forget the device
      TinyUSBDevice.attach();
    }
  }

#ifdef TINYUSB_NEED_POLLING_TASK
  TinyUSBDevice.task();
#endif
}

void handleTestMode() {
  // Optical channel sanity-check, characterisation and calibration mode. Mirrors the raw pin state of chA/chB/chC
  // onto 7-seg digits 0/1/2: top segment only when HIGH (beam clear), bottom segment only when LOW
  // (beam blocked). Lets the user slide the carriage by hand and watch channels respond live.
  // Tap REC to start recording a sweep (all decimal points lit), and tap again to stop and print what it measured
  // (sweep.h). Hold REC to calibrate from the recorded sweep: "CAL" saved, "Err" refused. Needs no serial connection.
  // Also streams the buffered sensor voltages for the Serial Plotter.
  const uint8_t channelPins[3] = { chA, chB, chC };
  static uint16_t sensorMv[NUM_CHANNELS];
  static unsigned long lastStreamMs = 0;
  static bool btnPressed, pressHandled, recording, haveSweep;
  static unsigned long btnChangedMs;

  // Mode entry
  if (mode != last_mode) {
    last_mode = mode;
    btnPressed = true;    // REC is still held from power-up,
    pressHandled = true;  // and that press is neither a tap nor a hold
    btnChangedMs = millis();
    recording = false;
    haveSweep = false;
    Serial.println("# Test mode. Tap REC to record a sweep, tap again to stop and print stats. Hold REC to calibrate from the sweep.");
    Serial.println("# Commands. A/B/C <mV> sets that channel's Vref (not saved), S toggles the stream, X clears the saved calibration.");
    printCalibration();
    showTestMessage(isCalibrated() ? WORD_CAL : WORD_DEF, TEST_STATUS_MS);
  }

  // REC: a tap starts or stops recording; a hold calibrates from the recorded sweep
  bool btnDown = digitalRead(btnRec) == 0;
  if (btnDown != btnPressed && millis() - btnChangedMs >= BTN_DEBOUNCE_MS) {
    btnPressed = btnDown;
    btnChangedMs = millis();
    if (btnPressed) {
      pressHandled = false;
    } else if (!pressHandled) {  // Released before the hold time: a tap
      if (recording) {
        recording = false;
        haveSweep = true;
        printTestSummary();
      } else {
        processEncoderChange();  // Sync previousState to the pins so the reset itself isn't counted
        positionCounter = 0;
        recoveredSkips = 0;
        lostCounts = 0;
        sweepBegin();
        recording = true;
      }
    }
  }
  if (btnPressed && !pressHandled && millis() - btnChangedMs >= CAL_HOLD_MS) {
    pressHandled = true;
    if (recording) {  // A hold also ends the recording
      recording = false;
      haveSweep = true;
      printTestSummary();
    }
    if (!haveSweep) Serial.println("# calibration=failed reason=no_sweep");
    bool saved = haveSweep && calibrateFromSweep();
    showTestMessage(saved ? WORD_CAL : WORD_ERR, TEST_RESULT_MS);
  }

  uint32_t pinUs = micros();  // The comparator states, then each sensor voltage, read back to back
  processEncoderChange();

  uint32_t adcUs[NUM_CHANNELS];
  for (uint8_t ch = 0; ch < NUM_CHANNELS; ch++) {
    uint32_t readStartUs = micros();
    sensorMv[ch] = readSensorMillivolts(ch);
    adcUs[ch] = readStartUs + (micros() - readStartUs) / 2;  // The middle of the oversampled read
  }
  // The recording freezes when it stops, so a later hold calibrates from exactly that sweep
  if (recording) sweepAdd(pinUs, currentState, adcUs, sensorMv);

  // Mirror the channels unless a status word is showing. All decimal points lit = recording.
  if (millis() - testMessageMs >= testMessageDurationMs) {
    uint8_t dp = recording ? 0x80 : 0;
    for (uint8_t i = 0; i < 3; i++) {
      if (digitalRead(channelPins[i]) == HIGH) {
        lc.setRow(0, i, 0x40 | dp);  // top segment only (HIGH = beam clear)
      } else {
        lc.setRow(0, i, 0x08 | dp);  // bottom segment only (LOW = beam blocked)
      }
    }
  }

  if (testStream && millis() - lastStreamMs >= TEST_STREAM_MS) {
    lastStreamMs = millis();
    Serial.printf("A:%u,B:%u,C:%u,VrefA:%u,VrefB:%u,VrefC:%u\n", sensorMv[CH_A], sensorMv[CH_B], sensorMv[CH_C],
                  getVref(CH_A), getVref(CH_B), getVref(CH_C));
  }

  handleSerialCommand();
}

// What one sweep measured. Per channel, in mV: min/max are the light/dark levels on BUFF_x; rise/fall are where the
// comparator switched at the Vref in force (hyst_src says whether they were measured), and the margins are how far the
// dark and light levels cleared them. duty is the fraction of each period it read light; half is the Vref that makes
// that half, and suggest is where the three Vrefs together space the edges best. Then the widths of the six encoder
// states in mm (ideally 1 each): from the comparators (hw), and simulated at the current (sim), half-duty (half) and
// suggested (suggest) Vrefs. Everything is key=value, so the Serial Plotter ignores it.
void printTestSummary() {
  SweepResult r;
  analyseSweep(r);
  uint16_t active[NUM_CHANNELS], half[NUM_CHANNELS], suggested[NUM_CHANNELS];
  bool haveSuggestion = true;
  for (uint8_t ch = 0; ch < NUM_CHANNELS; ch++) {
    const ChannelResult& c = r.ch[ch];
    active[ch] = c.vref;
    half[ch] = c.halfVref;
    suggested[ch] = c.suggestVref;
    haveSuggestion = haveSuggestion && c.suggestVref;
    Serial.printf("# %c min=%u max=%u span=%d mid=%u vref=%u rise=%d fall=%d hyst=%d edges=%u hyst_src=%s "
                  "dark_margin=%d light_margin=%d",
                  'A' + ch, c.lightMv, c.darkMv, c.darkMv - c.lightMv, (c.lightMv + c.darkMv) / 2, c.vref, c.riseMv,
                  c.fallMv, c.riseMv - c.fallMv, c.switchReadings, switchSourceName(c.switchSource),
                  c.darkMv - c.riseMv, c.fallMv - c.lightMv);
    printDuty("duty", c.duty);
    if (!c.halfVref) {
      Serial.printf(" suggest=none reason=%s\n", c.suggest == SUGGEST_NO_ROOM ? "no_room" : "short_sweep");
      continue;
    }
    Serial.printf(" half=%u%s", c.halfVref,
                  c.suggest == SUGGEST_LIGHT_BOUND  ? " clamped=light"
                  : c.suggest == SUGGEST_DARK_BOUND ? " clamped=dark"
                                                    : "");
    if (c.suggestVref) Serial.printf(" suggest=%u", c.suggestVref);
    Serial.println();
  }
  printSpacing("hw", active, r.hw);
  printSpacing("sim", active, r.simActive);
  if (haveSuggestion) {
    printSpacing("half", half, r.simHalf);
    printSpacing("suggest", suggested, r.simSuggest);
  }
  Serial.printf("# recovered=%u lost=%u position=%d\n", recoveredSkips, lostCounts, positionCounter);
}

// Shows a 3-letter status word on the 7-seg, pausing the test-mode channel mirror for durationMs
void showTestMessage(const uint8_t word[3], unsigned long durationMs) {
  lc.setRow(0, 2, word[0]);
  lc.setRow(0, 1, word[1]);
  lc.setRow(0, 0, word[2]);
  testMessageMs = millis();
  testMessageDurationMs = durationMs;
}

// Test-mode commands, one per line. "A 820" sets channel A's Vref to 820 mV until reset (not saved). "S" toggles the
// stream. "X" clears the saved calibration.
void handleSerialCommand() {
  static char line[16];
  static uint8_t len = 0;

  while (Serial.available()) {
    char c = Serial.read();
    if (c != '\n' && c != '\r') {
      if (len < sizeof(line) - 1) line[len++] = c;
      continue;
    }
    line[len] = '\0';
    len = 0;
    if (line[0] == '\0') continue;  // Blank line, or the second half of \r\n

    char cmd = toupper(line[0]);
    char* end;
    long mv = strtol(line + 1, &end, 10);
    if (cmd == 'S') {
      testStream = !testStream;
      Serial.printf("# stream=%s\n", testStream ? "on" : "off");
    } else if (cmd == 'X') {
      clearCalibration();
      showTestMessage(WORD_DEF, TEST_RESULT_MS);
    } else if (cmd >= 'A' && cmd <= 'C' && end != line + 1 && mv >= 0 && mv <= VDD_MV) {
      setVref(cmd - 'A', mv);
      Serial.printf("# Vref%c=%u mV (not saved)\n", cmd, getVref(cmd - 'A'));
    } else {
      Serial.println("# Commands. A/B/C <mV> sets that channel's Vref (not saved), S toggles the stream, X clears the saved calibration.");
    }
  }
}



void encoderISR() {
  timestamp = micros();
  stateChanged = true;
}

// Process encoder state change and update position, counting from the last valid state. A jump of two states is
// unambiguous in the Johnson sequence, so it counts instead of being lost: the loop missed a state, or two channels'
// edges crossed (passing through 010 or 101, which are held until the next valid state). Only a jump to the opposite
// state, whose direction is unknown, loses its count.
void processEncoderChange() {
  currentState = readEncoderState();
  if (currentState == previousState) return;

  int8_t step = johnsonStep(previousState, currentState);
  if (step == JOHNSON_INVALID) return;
  if (step == 3) {
    lostCounts++;
  } else {
    if (step == 2 || step == -2) recoveredSkips++;
    // Disable interrupts briefly while updating position
    noInterrupts();
    positionCounter += step;
    interrupts();
  }
  previousState = currentState;
}


// Callback invoked when received READ10 command.
// Copy disk's data to buffer (up to bufsize) and
// return number of copied bytes (must be multiple of block size)
int32_t msc_read_callback(uint32_t lba, void* buffer, uint32_t bufsize) {
  uint8_t const* addr = msc_disk[lba];
  memcpy(buffer, addr, bufsize);

  return bufsize;
}

// Callback invoked when received WRITE10 command.
// Process data in buffer to disk's storage and
// return number of written bytes (must be multiple of block size)
int32_t msc_write_callback(uint32_t lba, uint8_t* buffer, uint32_t bufsize) {
  uint8_t* addr = msc_disk[lba];
  memcpy(addr, buffer, bufsize);

  return bufsize;
}
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

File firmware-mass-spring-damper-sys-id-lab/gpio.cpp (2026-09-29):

#include "gpio.h"
#include "calibration.h"

#define VREF_PWM_FREQ_HZ 40000  // ~1.5 mV ripple after the 10k/1uF filter. The core's 1 kHz default gives ~60 mV, most of the 100 mV comparator hysteresis.
#define VREF_PWM_RANGE 4095     // 12-bit duty, 0.8 mV per step
#define VREF_SETTLE_MS 100      // 10 time constants of the 10k/1uF filter
#define ADC_OVERSAMPLE 8

// Position of each encoder state in the Johnson sequence 000 100 110 111 011 001, or -1 for the two it never visits
static const int8_t JOHNSON_INDEX[8] = { 0, 5, -1, 4, 1, -1, 2, 3 };

static const uint8_t pwmPins[NUM_CHANNELS] = { pwmA, pwmB, pwmC };
static const uint8_t buffPins[NUM_CHANNELS] = { buffA, buffB, buffC };
static uint16_t vrefMillivolts[NUM_CHANNELS];

void gpio_initialise() {
  pinMode(chA, INPUT);  // Comparator outputs have external 10k pull-ups. INPUT keeps the internal pull resistors disabled.
  pinMode(chB, INPUT);
  pinMode(chC, INPUT);

  pinMode(btnRec, INPUT_PULLUP);
  pinMode(ledRec, OUTPUT);

  analogReadResolution(12);  // The core defaults to 10-bit
  analogWriteFreq(VREF_PWM_FREQ_HZ);
  analogWriteRange(VREF_PWM_RANGE);
  uint16_t vrefs[NUM_CHANNELS] = { VREF_DEFAULT_MV, VREF_DEFAULT_MV, VREF_DEFAULT_MV };
  loadCalibration(vrefs);  // Replaces the defaults with this unit's saved thresholds, if it has been calibrated
  applyVrefs(vrefs);
}


// Set a comparator threshold. The filtered PWM voltage is duty * VDD.
void setVref(uint8_t channel, uint16_t millivolts) {
  vrefMillivolts[channel] = millivolts;
  analogWrite(pwmPins[channel], ((uint32_t)millivolts * VREF_PWM_RANGE + VDD_MV / 2) / VDD_MV);
}

// Set every comparator threshold, then wait for the RC filters to settle. Thresholds ramp from their previous level
// (0 V at power-up), and reading the encoder before they settle registers phantom counts.
void applyVrefs(const uint16_t millivolts[]) {
  for (uint8_t ch = 0; ch < NUM_CHANNELS; ch++) setVref(ch, millivolts[ch]);
  delay(VREF_SETTLE_MS);
}

uint16_t getVref(uint8_t channel) {
  return vrefMillivolts[channel];
}

// Buffered sensor voltage, averaged to reduce ADC noise. Ratiometric with the thresholds: both are referenced to +3V3.
uint16_t readSensorMillivolts(uint8_t channel) {
  uint32_t sum = 0;
  for (uint8_t i = 0; i < ADC_OVERSAMPLE; i++) sum += analogRead(buffPins[channel]);
  return sum * VDD_MV / (4096UL * ADC_OVERSAMPLE);
}

// Nominal BUFF_x voltage at which the comparator output switches LOW -> HIGH. The HIGH -> LOW point is
// COMPARATOR_HYST_MV below it.
uint16_t comparatorRiseMillivolts(uint16_t vref) {
  return ((uint32_t)vref * 34 + 16) / 33;
}


// Read current encoder state (3-bit value)
uint8_t readEncoderState() {
  uint8_t state = 0;

  // Read pins and construct 3-bit state (A=bit2, B=bit1, C=bit0)
  if (!digitalRead(chA)) state |= 0b100;  // PHOTO_x is LOW when its sensor sees a reflective surface
  if (!digitalRead(chB)) state |= 0b010;
  if (!digitalRead(chC)) state |= 0b001;

  return state;
}

// Signed steps along the Johnson sequence from prevState to currState: 0, +-1, +-2, or 3 when currState is the
// opposite state and the direction is unknown. JOHNSON_INVALID when either state is 010 or 101.
int8_t johnsonStep(uint8_t prevState, uint8_t currState) {
  int8_t from = JOHNSON_INDEX[prevState & 0b111], to = JOHNSON_INDEX[currState & 0b111];
  if (from < 0 || to < 0) return JOHNSON_INVALID;
  int8_t step = (to - from + 6) % 6;
  return step > 3 ? step - 6 : step;
}

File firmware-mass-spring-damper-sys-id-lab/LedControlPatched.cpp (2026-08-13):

/*
 *    LedControl.cpp - A library for controling Leds with a MAX7219/MAX7221
 *    Copyright (c) 2007 Eberhard Fahle
 * 
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
 *    This permission notice shall be included in all copies or 
 *    substantial portions of the Software.
 * 
 *    THE SOFTWARE IS PROVIDED "AS IS", WITHOUT WARRANTY OF ANY KIND,
 *    EXPRESS OR IMPLIED, INCLUDING BUT NOT LIMITED TO THE WARRANTIES
 *    OF MERCHANTABILITY, FITNESS FOR A PARTICULAR PURPOSE AND
 *    NONINFRINGEMENT. IN NO EVENT SHALL THE AUTHORS OR COPYRIGHT
 *    HOLDERS BE LIABLE FOR ANY CLAIM, DAMAGES OR OTHER LIABILITY,
 *    WHETHER IN AN ACTION OF CONTRACT, TORT OR OTHERWISE, ARISING
 *    FROM, OUT OF OR IN CONNECTION WITH THE SOFTWARE OR THE USE OR
 *    OTHER DEALINGS IN THE SOFTWARE.
 */


#include "LedControlPatched.h"

//the opcodes for the MAX7221 and MAX7219
#define OP_NOOP   0
#define OP_DIGIT0 1
#define OP_DIGIT1 2
#define OP_DIGIT2 3
#define OP_DIGIT3 4
#define OP_DIGIT4 5
#define OP_DIGIT5 6
#define OP_DIGIT6 7
#define OP_DIGIT7 8
#define OP_DECODEMODE  9
#define OP_INTENSITY   10
#define OP_SCANLIMIT   11
#define OP_SHUTDOWN    12
#define OP_DISPLAYTEST 15

LedControl::LedControl(int dataPin, int clkPin, int csPin, int numDevices) {
    SPI_MOSI=dataPin;
    SPI_CLK=clkPin;
    SPI_CS=csPin;
    if(numDevices<=0 || numDevices>8 )
        numDevices=8;
    maxDevices=numDevices;
    pinMode(SPI_MOSI,OUTPUT);
    pinMode(SPI_CLK,OUTPUT);
    pinMode(SPI_CS,OUTPUT);
    digitalWrite(SPI_CS,HIGH);
    SPI_MOSI=dataPin;
    for(int i=0;i<64;i++) 
        status[i]=0x00;
    for(int i=0;i<maxDevices;i++) {
        spiTransfer(i,OP_DISPLAYTEST,0);
        //scanlimit is set to max on startup
        setScanLimit(i,7);
        //decode is done in source
        spiTransfer(i,OP_DECODEMODE,0);
        clearDisplay(i);
        //we go into shutdown-mode on startup
        shutdown(i,true);
    }
}

int LedControl::getDeviceCount() {
    return maxDevices;
}

void LedControl::shutdown(int addr, bool b) {
    if(addr<0 || addr>=maxDevices)
        return;
    if(b)
        spiTransfer(addr, OP_SHUTDOWN,0);
    else
        spiTransfer(addr, OP_SHUTDOWN,1);
}

void LedControl::setScanLimit(int addr, int limit) {
    if(addr<0 || addr>=maxDevices)
        return;
    if(limit>=0 && limit<8)
        spiTransfer(addr, OP_SCANLIMIT,limit);
}

void LedControl::setIntensity(int addr, int intensity) {
    if(addr<0 || addr>=maxDevices)
        return;
    if(intensity>=0 && intensity<16)	
        spiTransfer(addr, OP_INTENSITY,intensity);
}

void LedControl::clearDisplay(int addr) {
    int offset;

    if(addr<0 || addr>=maxDevices)
        return;
    offset=addr*8;
    for(int i=0;i<8;i++) {
        status[offset+i]=0;
        spiTransfer(addr, i+1,status[offset+i]);
    }
}

void LedControl::setLed(int addr, int row, int column, boolean state) {
    int offset;
    byte val=0x00;

    if(addr<0 || addr>=maxDevices)
        return;
    if(row<0 || row>7 || column<0 || column>7)
        return;
    offset=addr*8;
    val=0b10000000 >> column;
    if(state)
        status[offset+row]=status[offset+row]|val;
    else {
        val=~val;
        status[offset+row]=status[offset+row]&val;
    }
    spiTransfer(addr, row+1,status[offset+row]);
}

void LedControl::setRow(int addr, int row, byte value) {
    int offset;
    if(addr<0 || addr>=maxDevices)
        return;
    if(row<0 || row>7)
        return;
    offset=addr*8;
    status[offset+row]=value;
    spiTransfer(addr, row+1,status[offset+row]);
}

void LedControl::setColumn(int addr, int col, byte value) {
    byte val;

    if(addr<0 || addr>=maxDevices)
        return;
    if(col<0 || col>7) 
        return;
    for(int row=0;row<8;row++) {
        val=value >> (7-row);
        val=val & 0x01;
        setLed(addr,row,col,val);
    }
}

void LedControl::setDigit(int addr, int digit, byte value, boolean dp) {
    int offset;
    byte v;

    if(addr<0 || addr>=maxDevices)
        return;
    if(digit<0 || digit>7 || value>15)
        return;
    offset=addr*8;
    v=pgm_read_byte_near(charTable + value); 
    if(dp)
        v|=0b10000000;
    status[offset+digit]=v;
    spiTransfer(addr, digit+1,v);
}

void LedControl::setChar(int addr, int digit, char value, boolean dp) {
    int offset;
    byte index,v;

    if(addr<0 || addr>=maxDevices)
        return;
    if(digit<0 || digit>7)
        return;
    offset=addr*8;
    index=(byte)value;
    if(index >127) {
        //no defined beyond index 127, so we use the space char
        index=32;
    }
    v=pgm_read_byte_near(charTable + index); 
    if(dp)
        v|=0b10000000;
    status[offset+digit]=v;
    spiTransfer(addr, digit+1,v);
}

void LedControl::spiTransfer(int addr, volatile byte opcode, volatile byte data) {
    //Create an array with the data to shift out
    int offset=addr*2;
    int maxbytes=maxDevices*2;

    for(int i=0;i<maxbytes;i++)
        spidata[i]=(byte)0;
    //put our device data into the array
    spidata[offset+1]=opcode;
    spidata[offset]=data;
    //enable the line 
    digitalWrite(SPI_CS,LOW);
    //Now shift out the data 
    for(int i=maxbytes;i>0;i--)
        shiftOut(SPI_MOSI,SPI_CLK,MSBFIRST,spidata[i-1]);
    //latch the data onto the display
    digitalWrite(SPI_CS,HIGH);
}    

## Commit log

2026-02-17 add final assembly image
2026-06-29 refer to screws as 'long' and 'short' for human readableness
2026-07-22 v1.1 as ordered
    [Case.stl, Guide-Rail-variant-hrs26-cwc13.stl, Guide-Rail-variant-hrs26-cwc15.stl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]
2026-08-13 add new (best) guide rail variant
    [Guide-Rail-variant-hrs20-cwc09.stl]
2026-08-13 v1.1 add test mode, patch LedControl library to suppress warnings
2026-08-15 Organise repo - documentation and structure
    [Case - Resin Print.stl, Guide Rail variant-hrs20-cwc09 - Resin Print.stl, Guide-Rail-variant-hrs26-cwc13.stl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]
2026-08-15 Organise repo - add spacers and RELEASING.md notes
    [Spacer - FDM or Resin Print.stl]
2026-08-27 update design with lessons learned from pilot production
    [carriage.kicad_pcb, main-board.kicad_pcb, main-board.kicad_sch]
2026-09-06 v2.0 PCB as ordered
    [main-board.kicad_pcb, main-board.kicad_sch]
2026-09-28 working calibration
2026-09-28 Stop tracking VS Code workspace settings
    .vscode/arduino.json held machine-specific values (serial port, a /tmp
    build path) and the VS Code Arduino extension rewrites it whenever a port
    or board option is picked. Ignore the whole .vscode/ folder; the board
    settings for building the firmware are in Programming-Instructions.md.
    Also correct the firmware compatibility note: the pilot run
    (release-2026-08-17) shipped main board v1.1, not rev 1.2.
2026-09-28 Calibrate encoder thresholds for edge spacing; count two-state jumps
    Board 1 worked on the 780 mV defaults. Calibrating it to each
    channel's light/dark midpoint (1090/1103/1157 mV) then left the
    all-dark state only 0.27 mm wide, and it threw invalid transitions.
    On a sensor whose light level clips, the midpoint makes every channel
    read light for more than half of each period, which pushes two
    channels' edges together.
    Calibration now aims for robust edge spacing instead:
    - Each channel's threshold targets 50% light duty, measured from the
    recorded sweep. When the 200 mV margin to the light or dark level
    holds a channel short of that, a search over the simulated sweep
    lets the other th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
    [calibration.cpp, firmware-mass-spring-damper-sys-id-lab.ino, gpio.cpp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]
2026-09-28 Add host tests for the calibration and decoder
    firmware-tests/ runs on a PC. It builds the sketch's sweep.cpp,
    calibration.cpp and gpio.cpp, plus the decoder copied out of the .ino,
    against small Arduino stand-ins:
    - The calibration test sweeps a synthetic encoder, with the expected
    answers taken from a physical model: 235 checks, including board 1
    fitted to its sweeps of 2026-09-28.
    - The decoder test drives processEncoderChange() through skipped
    states, crossed edges and random walks: 2011 checks.
    Run ./firmware-tests/run.sh. It exits non-zero on any failure.
    [calibration_test.cpp, decoder_test.cpp]
2026-09-29 Update Ordering-Instructions.md
    update cable tie
2026-09-29 add JLCPCB PCB + PCBA walkthrough

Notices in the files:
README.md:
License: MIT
